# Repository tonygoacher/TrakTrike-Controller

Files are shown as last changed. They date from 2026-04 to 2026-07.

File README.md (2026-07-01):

# TrakTrike-Controller

<p align="center">
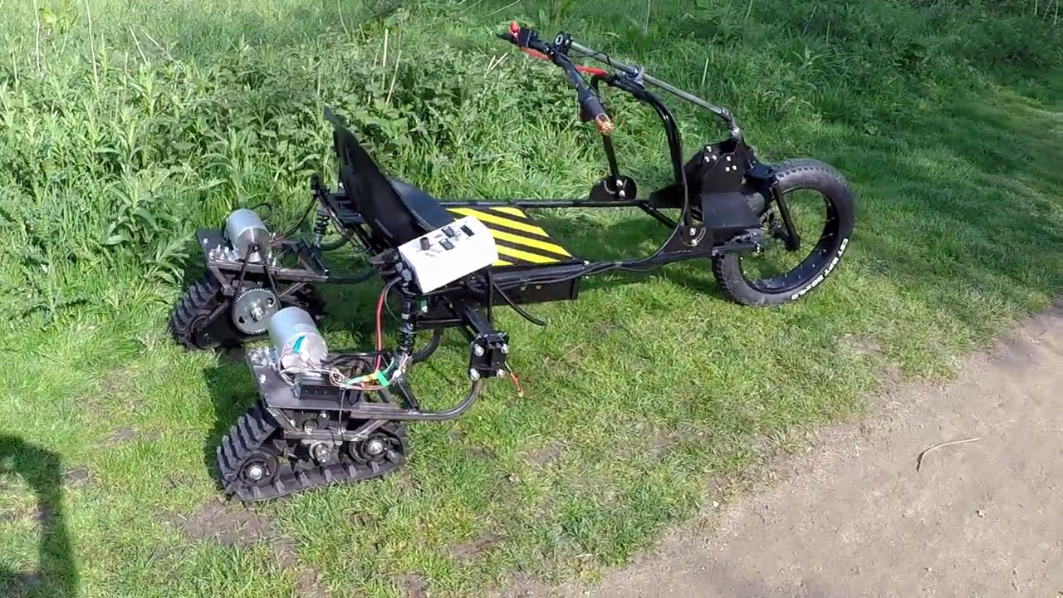
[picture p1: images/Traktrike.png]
  
</p>p>  

<p align="center">
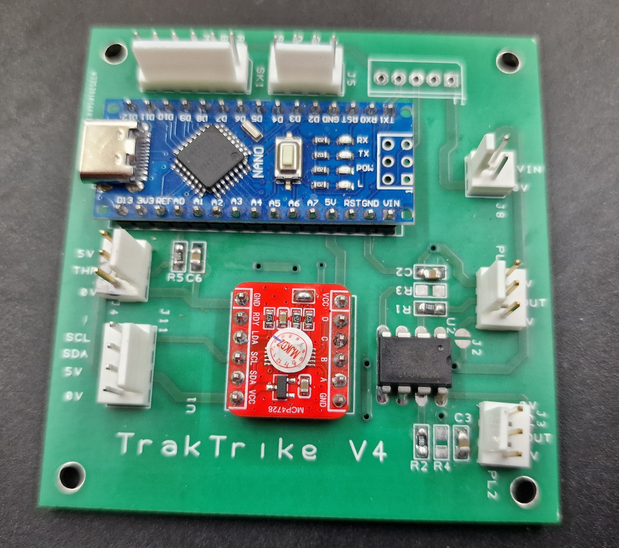
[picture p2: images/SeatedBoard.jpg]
  
</p>

Project files at: https://github.com/tonygoacher/TrakTrike-Controller

An Arduino Nano based dual-track pusher vehicle controller designed for dual motor drive platforms and similar projects that use low cost Aliexpress style BLDC motor controllers.

GCODE files for PCB manufacture and DesignSpark files are included.

The PCB is designed as a drop-in interface between the vehicle controls and a pair of BLDC motor controllers.

[I created TrakTrike, a electrically-driven dual-track sit-on trike for EMF camp 2022.](https://hackaday.io/project/205248-electric-tracked-tricycle-for-emf-camp)

Initially I used VESC75100 clones for the motor controllers. These gave me a great way of controlling accel/decel profiles on a per motor basis...but, I found them very fragile..having destroyed one pair just by changing some parameters and a second pair at WHY2025 for no reason I ever worked out.

At WHY2025 I met some members of [Hacky Racers](https://hackyracers.co.uk/) who suggested trying the inexpensive BLDC controllers available from AliExpress.

While these controllers were surprisingly robust and inexpensive, their low-speed throttle behaviour was poor. The vehicle was difficult to manoeuvre accurately OR SAFELY at low throttle positions.

TrakTrike-Controller was developed to solve that problem.

The controller transforms the behaviour of inexpensive BLDC controllers by providing configurable throttle shaping, ramp control and speed limiting.
The result is a tracked vehicle that is significantly easier and safer to manoeuvre at low speed.

The controller sits above the BLDC motor controllers and is responsible for:

- Throttle processing

- Drive profile management

- Track trim compensation

- Throttle Calibration

- Mode handling

- DAC output generation

The project uses an MCP4728 quad DAC to generate precise analogue throttle signals for independent left and right motor control.

---

# Features

## Drive Profiles

The controller supports multiple operating profiles:
| Profile | Purpose |
|--|--|
|Normal  | Full-speed operation |
|Slow | Manoeuvring mode |
| Reverse  | Reduced-speed reversing |
| Brake  | Rapid deceleration |
| Force | Calibration mode |

Profiles control:

- Throttle response curve

- Acceleration rate

- Deceleration rate

- Maximum DAC output

---

## Throttle Processing

Throttle input passes through several stages:

1. ADC filtering

2. Deadband removal

3. Soft take-up region

4. Configurable throttle curve

5. Ramp limiting

6. Trim compensation

---

## Track Trim Compensation

The controller uses a trim calibration table containing correction values across the throttle range. During operation, trim values are interpolated and

applied smoothly to compensate for differences between the left and right drive systems as the throttle moves through its full range.

---

## EEPROM Configuration

Configuration is stored in EEPROM and protected by:

- Version checking

- CRC validation

Stored settings include:

- DAC start values

- Maximum DAC values

- Slow mode DAC limits

- Throttle calibration

- Trim calibration table

---

## Why an MCP4728?

Many Arduino vehicle controllers generate throttle voltages using filtered PWM outputs.

This project uses an MCP4728 12-bit DAC instead.

Benefits include:

- True analogue outputs

- Higher resolution

- Repeatable calibration

- Independent left/right outputs

- No PWM ripple

---

# Hardware

## Tested Hardware

- Arduino Nano

- MCP4728 Quad DAC

- MCP6002 rail-to-rail op amp (this is used as a voltage follower to 'beef up' the DAC output)

- 16x2 I²C LCD

- Hall-effect twist throttle

- Brake switch

- Reverse switch

- Mode switch

- Dual motor controllers

## System Architecture

```

Twist Throttle

	  ↓

TrakTrike-Controller software

      ↓

MCP4728 DAC

      ↓

BLDC Motor Controllers

      ↓

Left / Right Tracks

```

---

# Operating Modes

## Normal Mode

Full-speed operation using the normal drive profile.

## Slow Mode

Used for precision manoeuvring with reduced maximum speed and gentler acceleration.

## Reverse Mode

Reverse operation automatically uses the slow profile to improve control and safety.

## Brake Mode

Highest-priority operating mode.

When active:

- Brake profile is selected

- Drive output is reset

- Vehicle decelerates rapidly

## Force Mode

Calibration mode used to apply a fixed throttle value independently of the twist throttle.

---

# Calibration Procedure

Connect the USB serial port of the arduino to a PC and run a monitor program (The one built into the Arduino IDE or PlatformIO is ok)

## Throttle Calibration Commands

```

**ENSURE THE VEHICLE IS LIFTED TO PREVENT MOVEMENT DURING THIS PROCEDURE. THE DRIVE MOTORS WILL BE ACTIVATED!**

cal min (Set the minimum throttle input value)

cal max (Set the maximum throttle input value)

cal apply (Apply the above calibration values with some sanity checks)

```

1. Set the physical throttle to its minumum setting

2. Issue the ```cal min ``` command.

3. Set the physical throttle to its maximum position.

4. Issue the ```cal max``` command.

5. Issue the ```cal apply``` command. This will ensure the min is greater than max and save the values to EEPROM.

## Start DAC calibration

**ENSURE THE VEHICLE IS LIFTED TO PREVENT MOVEMENT DURING THIS PROCEDURE. THE DRIVE MOTORS WILL BE ACTIVATED!**

Most BLDC controllers will begin to rotate the motor at some non-zero throttle voltage.

To maximise the throttle range we need to set the start values.

The procedure for left and right is the same. Note. If the motors are turning when the throttle is in the minimum position, your startdac value is too high!

Example: Setting the left side start DAC value

Issue the command

```startl 1000```

Did the motor turn? If no, repeat with higher values until it does, then gradually reduce the value until the motor no longer turns.

If the motor turns with ```startl 1000```, gradually reduce the value until it doesn't.

Repeat for right side using ```startr``` command.

When left and right start dac values have been found issue the

```show```

command to double check the values as printed. Then

```save```

to write to EEPROM.

## Max DAC calibration

**ENSURE THE VEHICLE IS LIFTED TO PREVENT MOVEMENT DURING THIS PROCEDURE. THE DRIVE MOTORS WILL BE ACTIVATED!**

Optional equipment: Tachometer

This sets the DAC output value at which the motors go at full speed. This reduces any 'dead' area where speed does not increase towards the maximum twist throttle position.

1. Disconnect the motor you are not testing.

2. Issue ```force 1.0``` command to set motor to full speed.

3. Issue ```dacmaxl nnnn``` or ```dacmaxr nnnn``` depending on which side you are calibrating where ```nnnn``` is an integer. Start at, say, 2000

4. Did the motor speed increase or decrease (I find this to be audibly detectable, but use a tacho if you wish). If it increases, repeat with a higher value until the motor speed does not increase, then reduce the value until it does. Find the minimum value above which there is no increase.

5. Repeat steps 1..4 for the other motor.

6. Issue ```save``` command to save these values to EEPROM.

## Trim Calibration Procedure

**Required equipment: tachometer**

By forcing the throttle value to a pre-defined set of values which define the interpolation points, the trim table is created .

**ENSURE THE VEHICLE IS LIFTED TO PREVENT MOVEMENT DURING TRIM. THE DRIVE MOTORS WILL BE ACTIVATED!**

Issue the ```show``` command. The device will print a table of the current trim points and the current trim values :

Trims:  
| Point   | Value  |
|--|--|
| 0.0  |  0.17|
|0.1  |0.19|
|0.2  |0.17  |
| 0.3 | 0.18 |
| 0.4 |0.19  |
|  0.5| 0.22 |
| 0.6 | 0.25 |
| 0.7 |0.24  |
| 0.8 |0.27|
| 0.9 |0.3|
|1.0  |0.31|

For each entry in the point column, issue a force command. e,g.

```force 0.5```

Measure left and right track RPM. Then issue the

```calibrate <leftRPM> <rightRPM>```

Command, eg

```calibrate 120 125```

Repeat for all rows. It's ok to go back to a previous point value and re-calibrate just that point.

When all points have been calibrated. Issue the ```show``` command to review the values. If all looks OK, issue the

```save``` command to write to EEPROM.

## Slow Mode Max DAC values

This is the value that sets the maximum voltage that the DAC will output at full throttle in slow mode. The default of 1500 is a sensible value for BLDC controllers but if your vehicle is too fast or too slow at max throttle, you can increase the value using the

```slowmaxl``` and ```slowmaxr``` commands.

e.g.

```slowmaxl 1500```

Sets the slow mode speed to 1500. 
Issue the
```save``` 
command to write to EEPROM.

Test the value on the vehicle and increase/decrease as required. I found it sensible to have both left and right values the same. You may need different values.

# Serial Commands

## Configuration

```text

load // Reload the current EEPROM settings

save // Save the current configuration to EEPROM

defaults // Restore all configuration values to defaults

show // Show the trim and DAC max values

showall // Show all config values. A lot of these can only be changed in the software.

```

## DAC Start Values

```text

startl 1060

startr 1060

```

## Maximum DAC Values

```text

dacmaxl 3500

dacmaxr 3500

```

## Slow Mode DAC Limits

```text

slowmaxl 1080

slowmaxr 1080

```

## Force Output

```text

force 0.25

force 0.50

force 0.75

```

---

# Safety Features

## Startup Throttle Inhibit

Some motor controllers refuse to operate if throttle voltage is present during startup.

To accommodate this behaviour, the controller forces both DAC outputs to 0V during power-up before normal operation begins.

## Throttle Fault Detection

Out-of-range throttle readings are detected automatically and result in zero throttle output.

## Configuration Validation

Stored settings are protected using:

- Version checking

- CRC validation

Invalid configurations automatically revert to defaults.

---

# Building

Developed using:

- PlatformIO

- Arduino Framework

- Arduino Nano

Required libraries:

- Adafruit MCP4728

- LiquidCrystal_I2C

Project-specific support classes:

- Switch

- SmoothBarGraph

- Pacer

---

# Project Status

This controller is actively used on a real tracked electric vehicle and continues to evolve through practical testing and field experience.

Contributions, bug reports and suggestions are welcome.

---

# License

This project is licensed under the MIT license.

---

*"Many design decisions in this project were driven by real-world testing rather than simulation."*

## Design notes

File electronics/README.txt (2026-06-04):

The design files were created with DesignSpark PCB
https://www.rs-online.com/designspark/pcb-software

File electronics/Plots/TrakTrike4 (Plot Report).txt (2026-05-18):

Plot Report
-----------

Report Written:     15:25 Wednesday, April 29, 2026
Project Path:       N:\TrakTrikeElectronics4\electronics\TrakTrike4.prj
Design Path:        N:\TrakTrikeElectronics4\electronics\TrakTrike4.pcb
Design Title:       
Created:            19/04/2026 11:54:32
Last Saved:         29/04/2026 15:24:48
Editing Time:       520 min
Units:              mm (precision 1)

Device Settings
===============

Gerber Settings
===============

    Leading zero suppression.
    G01 assumed throughout.
    Line termination <*> <CR> <LF>.
    3.5 format absolute inches.

    Format commands defined in Gerber file.
    Aperture table defined in Gerber file.
    Hardware arcs allowed.

Drill Settings
==============

    Excellon Format 2
    Format 3.5 absolute in mm.
    Zero suppression Leading

Plots Output
============

    Plot Job: "N:\TrakTrikeElectronics4\electronics\TrakTrike4.mop"

Gerber Output
=============

N:\TrakTrikeElectronics4\electronics\Plots\TrakTrike4 - Top Silkscreen.gbr

    Layers:
    ------------------
    Top Silkscreen

    D-Code Shape  (thou)
    -----------------------
    D10    Round 7.87
    D11    Round 11.81
    D12    Round 5.00
    D13    Round 1.00
    D14    Round 10.00

Gerber Output
=============

N:\TrakTrikeElectronics4\electronics\Plots\TrakTrike4 - Top Copper.gbr

    Layers:
    ------------------
    Top Copper
    Board Outlines

    D-Code Shape  (thou)
    --------------------------------------------------
    D12    Round 5.00
    D15    Round 50.00
    D16    Round 31.50
    D17    Round 56.00
    D18    Round 48.00
    D19    Round 137.80
    D70    Rectangle 59.06 X 98.43  Rotation 90
    D71    Oval 59.06 X 98.43  Rotation 90
    D20    Rounded Rectangle 66.93 X 118.11 X 23.62
    D21    Rectangle 66.93 X 118.11
    D22    Oval 60.00 X 110.00  Rotation 90
    D23    Rectangle 70.87 X 118.11
    D24    Oval 70.87 X 118.11
    D25    Bullet 78.74 X 39.37  Rotation 270
    D26    Round 78.74
    D27    Bullet 78.74 X 39.37  Rotation 90
    D28    Rectangle 55.00 X 60.00
    D29    Rectangle 55.00 X 60.00  Rotation 90
    D72    Rectangle 62.99 X 137.80  Rotation 90
    D73    Oval 62.99 X 137.80  Rotation 90
    D74    Rectangle 62.99 X 137.80
    D75    Oval 62.99 X 137.80
    D76    Rectangle 78.74 X 118.11  Rotation 90
    D77    Oval 78.74 X 118.11  Rotation 90
    D78    Square 78.74
    D79    Octagon 78.74

Gerber Output
=============

N:\TrakTrikeElectronics4\electronics\Plots\TrakTrike4 - Top Copper (Resist).gbr

    Layers:
    --------------
    Top Copper

    D-Code Shape  (thou)
    --------------------------------------------------
    D80    Round 147.80
    D81    Rectangle 69.06 X 108.43  Rotation 90
    D82    Oval 69.06 X 108.43  Rotation 90
    D83    Rounded Rectangle 66.93 X 118.11 X 23.62
    D84    Rectangle 76.93 X 128.11
    D85    Oval 70.00 X 120.00  Rotation 90
    D86    Rectangle 80.87 X 128.11
    D87    Oval 80.87 X 128.11
    D88    Bullet 88.74 X 49.37  Rotation 270
    D89    Round 88.74
    D90    Bullet 88.74 X 49.37  Rotation 90
    D91    Rectangle 65.00 X 70.00
    D92    Rectangle 65.00 X 70.00  Rotation 90
    D93    Rectangle 72.99 X 147.80  Rotation 90
    D94    Oval 72.99 X 147.80  Rotation 90
    D95    Rectangle 72.99 X 147.80
    D96    Oval 72.99 X 147.80
    D97    Rectangle 88.74 X 128.11  Rotation 90
    D98    Oval 88.74 X 128.11  Rotation 90
    D99    Square 88.74
    D100   Octagon 78.74

Gerber Output
=============

N:\TrakTrikeElectronics4\electronics\Plots\TrakTrike4 - Top Paste Mask.gbr

    Layers:
    ------------------
    Top Paste Mask

    D-Code Shape  (thou)
    ----------------------------------------------
    D101   Bullet 72.74 X 33.37  Rotation 270
    D102   Round 72.74
    D103   Bullet 72.74 X 33.37  Rotation 90
    D104   Rectangle 49.00 X 54.00
    D105   Rectangle 49.00 X 54.00  Rotation 90

Gerber Output
=============

N:\TrakTrikeElectronics4\electronics\Plots\TrakTrike4 - Bottom Copper.gbr

    Layers:
    -----------------
    Bottom Copper

    D-Code Shape  (thou)
    --------------------------------------------------
    D15    Round 50.00
    D16    Round 31.50
    D17    Round 56.00
    D18    Round 48.00
    D19    Round 137.80
    D70    Rectangle 59.06 X 98.43  Rotation 90
    D71    Oval 59.06 X 98.43  Rotation 90
    D20    Rounded Rectangle 66.93 X 118.11 X 23.62
    D21    Rectangle 66.93 X 118.11
    D22    Oval 60.00 X 110.00  Rotation 90
    D23    Rectangle 70.87 X 118.11
    D24    Oval 70.87 X 118.11
    D28    Rectangle 55.00 X 60.00
    D29    Rectangle 55.00 X 60.00  Rotation 90
    D72    Rectangle 62.99 X 137.80  Rotation 90
    D73    Oval 62.99 X 137.80  Rotation 90
    D74    Rectangle 62.99 X 137.80
    D75    Oval 62.99 X 137.80
    D76    Rectangle 78.74 X 118.11  Rotation 90
    D77    Oval 78.74 X 118.11  Rotation 90
    D78    Square 78.74
    D79    Octagon 78.74

Gerber Output
=============

N:\TrakTrikeElectronics4\electronics\Plots\TrakTrike4 - Bottom Silkscreen.gbr

    Layers:
    ---------------------
    Bottom Silkscreen

    D-Code Shape  (thou)
    -----------------------
    D12    Round 5.00

Gerber Output
=============

N:\TrakTrikeElectronics4\electronics\Plots\TrakTrike4 - Bottom Solder Mask.gbr

    Layers:
    ----------------------
    Bottom Solder Mask

    D-Code Shape  (thou)
    --------------------------------------------------
    D106   Round 62.00
    D107   Round 54.00
    D108   Round 143.80
    D109   Rectangle 65.06 X 104.43  Rotation 90
    D110   Oval 65.06 X 104.43  Rotation 90
    D111   Rounded Rectangle 66.93 X 118.11 X 23.62
    D112   Rectangle 72.93 X 124.11
    D113   Oval 66.00 X 116.00  Rotation 90
    D114   Rectangle 76.87 X 124.11
    D115   Oval 76.87 X 124.11
    D116   Rectangle 61.00 X 66.00  Rotation 90
    D117   Rectangle 61.00 X 66.00
    D118   Rectangle 68.99 X 143.80  Rotation 90
    D119   Oval 68.99 X 143.80  Rotation 90
    D120   Rectangle 68.99 X 143.80
    D121   Oval 68.99 X 143.80
    D122   Rectangle 84.74 X 124.11  Rotation 90
    D123   Oval 84.74 X 124.11  Rotation 90
    D124   Square 84.74
    D125   Octagon 78.74

Gerber Output
=============

N:\TrakTrikeElectronics4\electronics\Plots\TrakTrike4 - Bottom Paste Mask.gbr

    Layers:
    ---------------------
    Bottom Paste Mask

    D-Code Shape  (thou)
    ----------------------------------------------
    D104   Rectangle 49.00 X 54.00
    D105   Rectangle 49.00 X 54.00  Rotation 90

Gerber Output
=============

N:\TrakTrikeElectronics4\electronics\Plots\TrakTrike4 - Gerber Drill Data - [Through Hole].gbr

    Layers:
    ------------------
    [Through Hole]

    D-Code Shape  (thou)
    -----------------------
    D126   Round 32.00
    D127   Round 24.00
    D128   Round 125.98
    D129   Round 39.37
    D130   Round 43.31
    D131   Round 35.00

NC Drill Output
===============

N:\TrakTrikeElectronics4\electronics\Plots\TrakTrike4 - NC Drill Data - [Through Hole].drl

    Output:
    ---------------------------
    Plated Round Drill Holes
    Plated Slots

    Tool  Size           Count   ID
    --------------------------------------
    T001  0.02400 inches 1     A
    T002  0.03200 inches 17    F
    T003  0.03500 inches 5     D
    T004  0.03937 inches 56    H
    T005  0.04331 inches 11    P
    T006  0.12598 inches 4     C
    --------------------------------------
    Total                94
    --------------------------------------

N:\TrakTrikeElectronics4\electronics\Plots\TrakTrike4 - NC Drill Data - [Through Hole] (Unplated).drl

    Output:
    -----------------------------
    Unplated Round Drill Holes
    Unplated Slots

    Tool  Size Count   ID
    ----------------------------
    ----------------------------
    Total      0
    ----------------------------

End Of Report.

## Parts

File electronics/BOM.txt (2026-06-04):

C1..C6 0.1uF 0805 
R1, R2	1K 1% 0805
R3, R4 (optional) 10K 1% 0805
U1 MCP4728 DAC module. (https://www.aliexpress.com/item/1005010677659091.html)
U2 MCP6002 8 pin DIP. Make sure you get these from a reliable source. I got fake ones off AliExpress and they do not have full rail to rail output.
U3 Arduino Nano 

Apologies for all the oddball connector identifiers!

J1 Molex KK 5 way header 22-27-2051
J11, J5 Molex KK 254 4 way header 22-23-2041 
PL1, PL2, J4 Molex 3 way KK 254 3 way header 22-27-2031
SK1 Molex KK 254 6 way header 22-27-2061
J8 Molex KK 254 2 way header 22-23-2021

2.54 mm strip headers for Arduino and DAC x 4
https://www.aliexpress.com/item/1005006034877497.html

LCD1602 I2C line LCD display  https://www.aliexpress.com/item/1005006964073869.html

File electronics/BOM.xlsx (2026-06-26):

 |  |  | xxxx xxxx xxxxx xxPCS BOM (Sample Bill of Materials)
Item # | *Designator | *Qty | Manufacturer | *Mfg Part # | Description / Value | *Package/Footprint | Type | Your Instructions / Notes
1 | U1 | 1 | Aliexpress | MCP4728 DAC Module | MCP4728 DAC Module.DIP Format | PDIP 12 | thru-hole | https://www.aliexpress.com/item/1005010705047519.html
2 | U2 | 1 | Microchip | MP6002 | Dual Op Amp 8 pin DIP | DIP | thru-hole
3 | U3 | 1 | Arduino | "7630049200173" | Arduino Nano 3.x | DIP | thru-hole
4 | C1-C6 | 6 | Kyocera AVX | 08055C104JAT2A | 0.1uF Ceramic capacitor SMD 5% | 805 | SMD
5 | R1,R2 | 2 | PANASONIC | ERA6ARB102V | 1K SMD Chip resistor 0.1% | 805 | SMD
6 | R3,R4 | 2 | VISHAY | TNPW080510K0BEEA | 10K SMD Chip resistor 0.1% | 805 | SMD
7 | J1 | 1 | Molex | 22-27-2051 | 5 way 2.54" square pin Header | SIL5 | thru-hole
8 | J11, J5 | 1 | Molex | 22-23-2041 | 4 way 2.54" square pin header | SIL4 | thru-hole
9 | PL1, PL2 , J4 | 3 | Molex | 22-27-2031 | 3 way 2.54" square pin header | SIL3 | thru-hole
10 | J8 | 1 | Molex | 22-23-2021 | 2 way 2.54" square pin header | SIL2 | thru-hole
11 | SK1 | 1 | Molex | 22-27-2061 | 6 way 2.54" square pin header
12
13
14
15
Need a quick and accurante quote? Need an efficient production? Please read SMT Ordering Necessary Files & Info in 1 minute. Thank you very much! (https://www.pcbway.com/smt_ordering_guide.html)
Click for Instructions on How to Create a BOM (https://www.pcbway.com/blog/PCB_Assembly/How_to_Build_a_BOM__Bill_Of_Materials_.html)

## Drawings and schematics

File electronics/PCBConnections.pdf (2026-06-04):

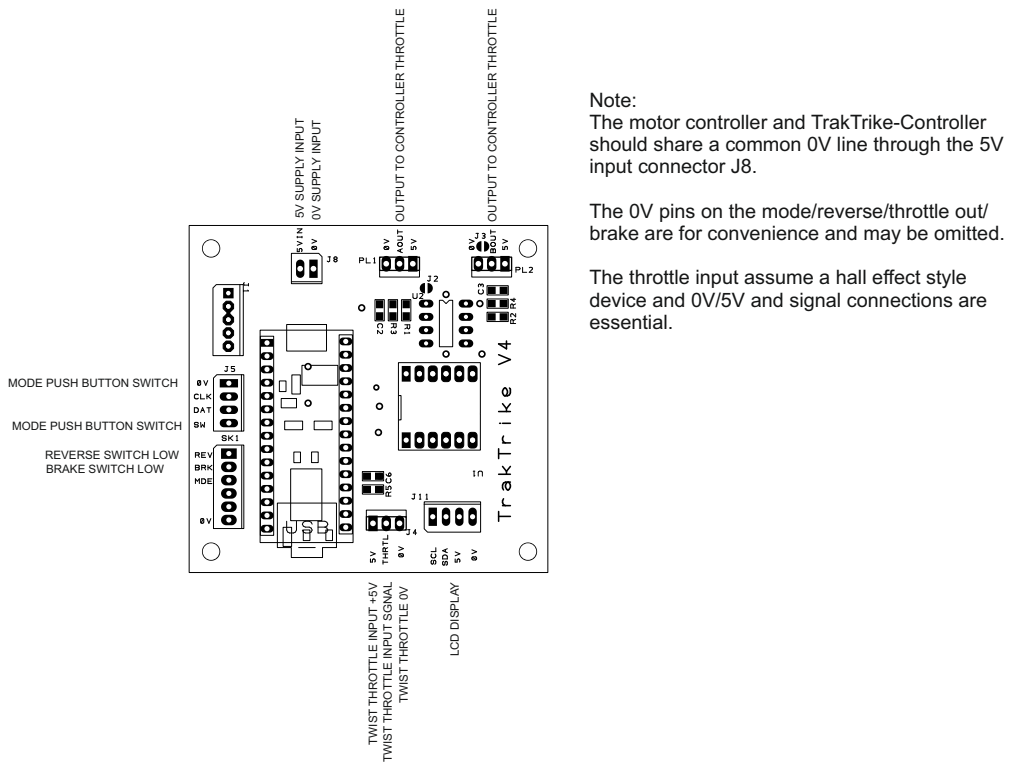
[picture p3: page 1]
TWIST THROTTLE 0V; LCD DISPLAY; 5V SUPPLY INPUT; 0V SUPPLY INPUT; TrakTrike-Controller

OUTPUT TO CONTROLLER THROTTLE

Note:
The motor controller and
should share a common 0V line through the 5V
input connector J8.

The 0V pins on the mode/reverse/throttle out/
brake are for convenience and may be omitted.

The throttle input assume a hall effect style
device and 0V/5V and signal connections are
essential.

MODE PUSH BUTTON SWITCH

REVERSE SWITCH LOW
BRAKE SWITCH LOW

TWIST THROTTLE INPUT +5V

TWIST THROTTLE INPUT SGNAL

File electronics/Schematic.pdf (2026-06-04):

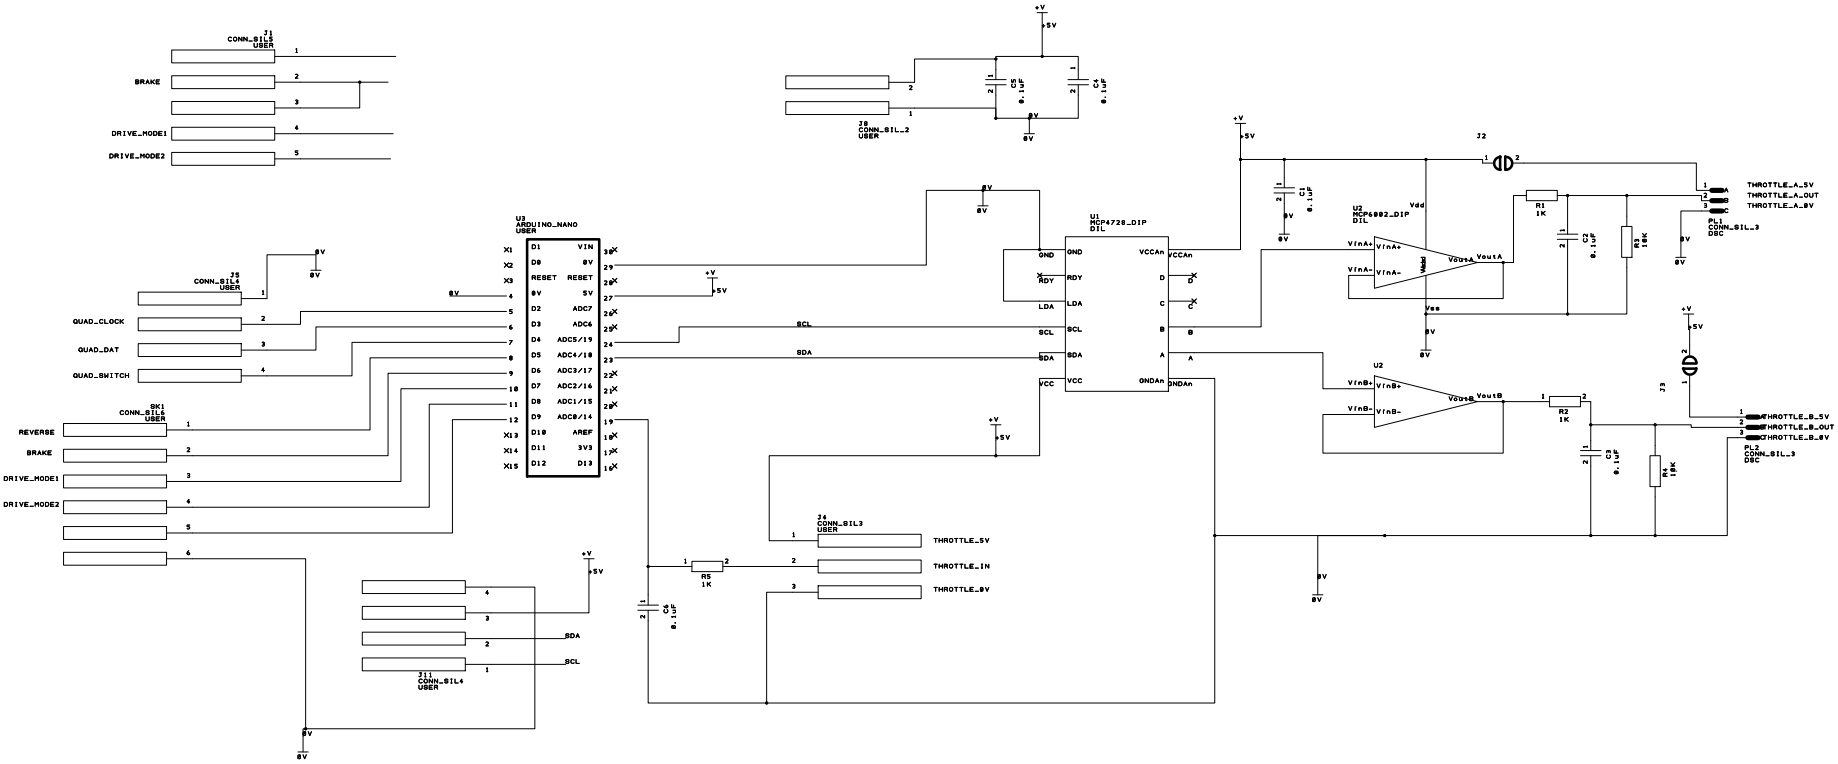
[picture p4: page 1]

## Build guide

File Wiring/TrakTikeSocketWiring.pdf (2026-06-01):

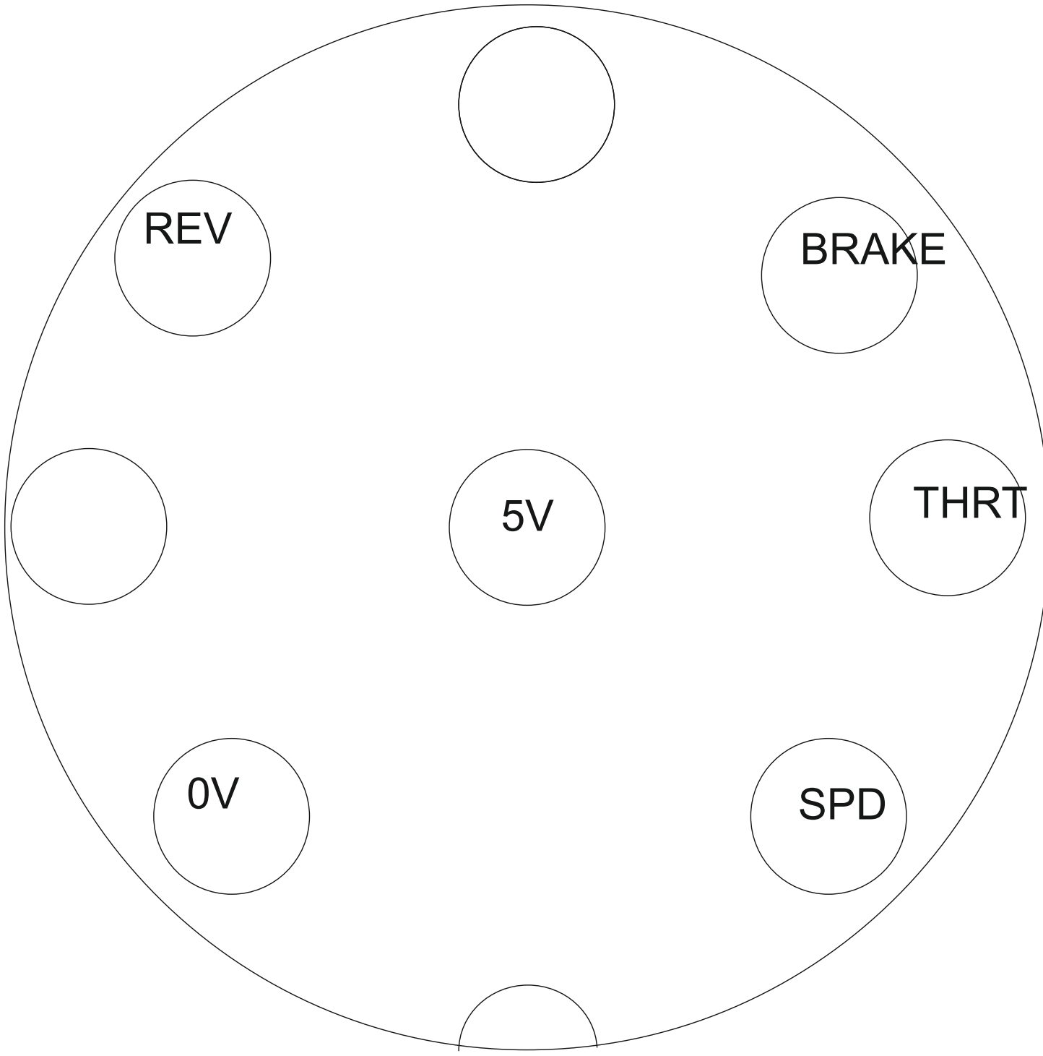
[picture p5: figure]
SPD; THRT; BRAKE REV

Looking into back of
M12 socket

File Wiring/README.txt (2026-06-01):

This is all intended for my use. Please ignore.

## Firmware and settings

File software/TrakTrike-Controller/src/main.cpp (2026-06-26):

/******************************************************************************
 *
 *  TrakTrike-Controller
 *
 *  An Arduino Nano based dual-track vehicle controller for tracked electric
 *  vehicles, skid-steer platforms and similar projects using analogue
 *  throttle controlled BLDC motor controllers.
 *
 *  Features:
 *      - Configurable throttle shaping
 *      - Multiple drive profiles
 *      - Track trim calibration and interpolation
 *      - Dual MCP4728 DAC outputs
 *      - EEPROM configuration storage
 *      - Throttle calibration and diagnostics
 *
 *  Author:
 *      Tony Goacher
 *
 *  Project:
  *     https://github.com/tonygoacher/TrakTrike-Controller
 *
 *  Copyright:
 *      Copyright (c) 2026 Tony Goacher
 *
 *  License:
 *      Released under the MIT License.
 *
 *  Disclaimer:
 *      This software controls equipment capable of movement and may cause
 *      injury, death, or property damage if used incorrectly.
 *
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
 *      Users are solely responsible for ensuring that the software and hardware is
 *      suitable for their application and that appropriate safety measures
 *      are implemented and tested before use.
 *
 *      Always test with drive wheels or tracks lifted clear of the ground
 *      before operating a vehicle under software control.
 *
 ******************************************************************************/

#include <Arduino.h>
#include <EEPROM.h>
#include <Wire.h>
#include <stddef.h>


#include <LiquidCrystal_I2C.h>
#include <math.h>
#include <Adafruit_MCP4728.h>
#include "ports.h"

#include "Switch.h"
#include "SmoothBarGraph.h"
#include "Pacer.h"



// =====================
// MCP4728
// =====================
Adafruit_MCP4728 mcp;
constexpr int   MinDACValue = 0;
constexpr int   MaxDACValue = 4095;
constexpr float DAC_VREF    = 4.7f;

// =====================
// CONFIG
// =====================
#define EEPROM_ADDR 0
#define PARAM_VERSION 7
#define NUM_TRIM_VALUES 11

#define STATS_UPDATE_MS 1000    // Update stats this many ms
#define BARGRAPH_UPDATE_MS 100  // Update bargraph this many ms

LiquidCrystal_I2C lcd(0x27,16,2);  // set the LCD address to 0x27 for a 16 chars and 2 line display
SmoothBarGraph barGraph(lcd,6,1,10);

struct DriveProfile
{
    float curveExponent;
    float rampUp;
    float rampDown;
};




DriveProfile normalProfile =
{
    1.3f,   // curve
    0.05f,  // ramp up
    0.8f    // ramp down
};

DriveProfile slowProfile =
{
    1.5f,   // softer curve
    0.005f,  // gentler ramp
    0.15f    // Ramp down
};

DriveProfile brakeProfile =
{
    0.0f,   // softer curve
    0.0f,  // gentler ramp
    1.0f    // HArd decel
};


// Use force command to set these values Then measure both motor speeds.
// The use calibrate lefftrpm rightrpm to set the TRIM_VALUE entry. Index into TRIM_VALUE is calculated automatically
const float trimThrottlePoints[NUM_TRIM_VALUES] =
{
    0.0f,
    0.1f,
    0.2f,
    0.3f,
    0.4f,
    0.5f,
    0.6f,
    0.7f,
    0.8f,
    0.9f,
    1.0f
};

// This can be used to override the twist throttle value during trim calibration. BRAKEMODE overrides this.
float FORCE_OUTPUT  = 0.0f;

// Default trim calibration values. These are for my EV. 
// You probably need to do the calibration routine to find your defaults
const float defaultCalibration[NUM_TRIM_VALUES] = 
{
    0.17,
    -0.16,
    0.03,
    0.08,
    0.12,
    0.19,
    0.16,
    0.10,
    0.17,
    0.17,
    0.17,
};

enum TRACK_ID
{
    LEFT = 0,
    RIGHT = 1
};

enum SystemMode
{
    SLOWMODE = 1,
    BRAKEMODE = 2,
    REVERSEMODE = 4,
    FORCEMODE = 8,
    MODECHANGE = 16,
 

    INIT = 0xff
};

// Pending mode state being assembled by SetModes().
// Changes are committed to systemMode by
// displayNewSystemMode() after one-shot actions
// (LCD updates, output resets, etc.) have been performed.
uint8_t newSystemMode = SystemMode::SLOWMODE; 

// Current active mode state.
// Used to detect mode transitions and drive the LCD display.
uint8_t currentSystemMode = SystemMode::INIT;  

 // When changing mode, force the throttle to zero for 500ms or continuously until throttle released
// This prevents unwanted movement if reverse is enabled at none aero throttle
Pacer modePacer(false,500);   

typedef struct {
    uint8_t  version;
    uint16_t crc;
} config_header_t;

struct settings_t
{
    int LEFT_DAC_START;
    int LEFT_DAC_MAX;
    int LEFT_SLOW_DAC_MAX;
    int RIGHT_DAC_START;
    int RIGHT_DAC_MAX;
    int RIGHT_SLOW_DAC_MAX;
    int LEFT_DEFAULT;
    int RIGHT_DEFAULT;

    float THROTTLE_DEADBAND;
    float TAKEUP_END;

    float TRIM_VALUES[NUM_TRIM_VALUES];


    int THROTTLE_MIN_ADC;
    int THROTTLE_MAX_ADC;
    uint8_t DAC_DEFAULT_WRITTEN;       // This is used to track if the default DAC output has been written to the DAC EEPROM
};

struct Config {
    config_header_t header;
    settings_t  settings;
   
};

Config cfg;



// Declare forward refs
void  loadDefaults();


void printTrimValues( const float v[NUM_TRIM_VALUES])
{
    for(int i = 0 ; i < NUM_TRIM_VALUES ; i++)
    {   
       Serial.println(v[i]);
    }
}

// =====================
// THROTTLE CLASS
// =====================
class TwistThrottle {
public:
    struct Config {
        int minADC;
        int maxADC;
        int deadband;
        float filterAlpha;
        float maxRate;
    };

    void begin(const Config& cfg) {
        config = cfg;
        filtered = config.minADC;
        lastOutput = 0.0f;
        lastTime = millis();
    }

    float GetThrottle() {

        int raw = analogRead(THROTTLE);

        int validMin = config.minADC - 20;
        int validMax = config.maxADC + 20;

        if (raw < validMin || raw > validMax) 
        { 
            fault = true; return 0.0f; 
        }

        fault = false;

        filtered += (raw - filtered) * config.filterAlpha;

        if (filtered < (config.minADC + config.deadband)) {
            return applyRateLimit(0.0f);
        }

        float output = (filtered - (config.minADC + config.deadband)) /
                       (float)(config.maxADC - (config.minADC + config.deadband));

        output = constrain(output, 0.0f, 1.0f);

        return applyRateLimit(output);
    }

    bool isFault() const {
        return fault;
    }

private:
    Config config;

    float filtered = 0.0f;
    float lastOutput = 0.0f;
    unsigned long lastTime = 0;

    bool fault = false;

    float applyRateLimit(float target) {

        if (config.maxRate <= 0.0f)
            return target;

        unsigned long now = millis();
        float dt = (now - lastTime) / 1000.0f;
        lastTime = now;

        float maxDelta = config.maxRate * dt;
        float delta = target - lastOutput;

        if (delta > maxDelta) delta = maxDelta;
        if (delta < -maxDelta) delta = -maxDelta;

        lastOutput += delta;

        return lastOutput;
    }
};

TwistThrottle throttle;

// =====================
// CALIBRATION STATE
// =====================
struct ThrottleCal {
    int minADC = 1023;
    int maxADC = 0;
};

ThrottleCal throttleCal;

// =====================
// STATE
// =====================

String inputString = "";
Switch modeSwitch(MODE);


// =====================
// FORWARD DECLARATIONS
// =====================
void processCommand(String cmd);
void updateDACDefaults();
void applyCalibration();
void configureThrottle();
void printParams();

void printAll(const Config& cfg)
{
    Serial.println(F("===== CONFIG ====="));

    Serial.print(F("Version: "));
    Serial.println(cfg.header.version);

    Serial.print(F("CRC: "));
    Serial.println(cfg.header.crc);

    Serial.println();

    Serial.print(F("LEFT DAC_START: "));
    Serial.println(cfg.settings.LEFT_DAC_START);
    Serial.print(F("RIGHT DAC_START: "));
    Serial.println(cfg.settings.RIGHT_DAC_START);    

    Serial.print(F("LEFT_DAC_MAX: "));
    Serial.println(cfg.settings.LEFT_DAC_MAX);
    
    Serial.print(F("LEFT_SLOW_DAC_MAX: "));
    Serial.println(cfg.settings.LEFT_SLOW_DAC_MAX);

    Serial.print(F("RIGHT DAC_MAX: "));
    Serial.println(cfg.settings.RIGHT_DAC_MAX);

    Serial.print(F("RIGHT_SLOW_DAC_MAX: "));
    Serial.println(cfg.settings.RIGHT_SLOW_DAC_MAX);

    Serial.println();

    Serial.print(F("THROTTLE_DEADBAND: "));
    Serial.println(cfg.settings.THROTTLE_DEADBAND, 4);

    Serial.print(F("TAKEUP_END: "));
    Serial.println(cfg.settings.TAKEUP_END, 4);

    Serial.println();

    Serial.println();

    Serial.println(F("Config trim values"));
    printTrimValues( cfg.settings.TRIM_VALUES);
    

    Serial.print(F("THROTTLE_MIN_ADC: "));
    Serial.println(cfg.settings.THROTTLE_MIN_ADC);

    Serial.print(F("THROTTLE_MAX_ADC: "));
    Serial.println(cfg.settings.THROTTLE_MAX_ADC);

    Serial.println(F("=================="));
}

// =====================
// CRC
// =====================
uint16_t calculateCRC(const settings_t &cfg) {
    const uint8_t *data = (const uint8_t*)&cfg;

    size_t len   = sizeof(settings_t) ;

    uint16_t crc = 0;

    for (size_t i = 0; i < len; i++) {
        crc += data[i];
    }

    return crc;
}

// =====================
// CONFIG APPLY
// =====================
void applyConfig(const Config &new_cfg) {

    
    cfg = new_cfg;
    printAll(cfg);
}

// =====================
// CONFIG SAVE/LOAD
// =====================
void saveConfig() {
  

    cfg.header.version = PARAM_VERSION;


    cfg.header.crc = calculateCRC(cfg.settings);

    EEPROM.put(EEPROM_ADDR, cfg);

    Serial.println("Saved config");
}

bool loadConfig() {
    Config loadedConfig;
    EEPROM.get(EEPROM_ADDR, loadedConfig);

    if (loadedConfig.header.version != PARAM_VERSION) 
    {
        Serial.println("Config version mismatch. Using defaults");
        loadDefaults();
        saveConfig();
        return false;
    }

    if (calculateCRC(loadedConfig.settings) != loadedConfig.header.crc)
    {
      Serial.println("Config load failed CRC. Using defaults");
      loadDefaults();
      saveConfig();
      return false;
    }      

    applyConfig(loadedConfig);

    Serial.println("Loaded config");
    return true;
}

void loadDefaults() {

     cfg.header.version = PARAM_VERSION;
     cfg.header.crc = 0;    // This will be set in the save routine.
     cfg.settings.LEFT_DAC_START = 1060;
     cfg.settings.RIGHT_DAC_START = 1060;
     cfg.settings.LEFT_DAC_MAX = 3500;
     cfg.settings.RIGHT_DAC_MAX = 3500;
     cfg.settings.LEFT_SLOW_DAC_MAX = 1500;
    
     cfg.settings.RIGHT_SLOW_DAC_MAX = 1500;

     cfg.settings.THROTTLE_DEADBAND = 0.05f;
     cfg.settings.TAKEUP_END = 0.20f;


    for(int i = 0 ; i < NUM_TRIM_VALUES ; i++)
    {
         cfg.settings.TRIM_VALUES[i] = defaultCalibration[i];
    }


     cfg.settings.THROTTLE_MIN_ADC = 177;
     cfg.settings.THROTTLE_MAX_ADC = 808;

     cfg.settings.DAC_DEFAULT_WRITTEN = 0;

    Serial.println("Loaded defaults");
    printParams();
    
}

// =====================
// THROTTLE SETUP
// =====================
void configureThrottle() {

    TwistThrottle::Config throttleConfig;

    throttleConfig.minADC =  cfg.settings.THROTTLE_MIN_ADC;
    throttleConfig.maxADC =  cfg.settings.THROTTLE_MAX_ADC;

    throttleConfig.deadband = 8;
    throttleConfig.filterAlpha = 0.1f;
    throttleConfig.maxRate = 0.0f;


    throttle.begin(throttleConfig);
}

// =====================
// CALIBRATION
// =====================


void captureMin() {
    throttleCal.minADC = analogRead(THROTTLE);
    Serial.print(F("Min captured: ")); Serial.println(throttleCal.minADC);
}

void captureMax() {
    throttleCal.maxADC = analogRead(THROTTLE);
    Serial.print(F("Max captured: ")); Serial.println(throttleCal.maxADC);
}

/**
 * Apply the most recently captured throttle calibration values.
 *
 * The calibration process records the minimum and maximum ADC readings
 * observed while the throttle is moved through its full travel. This
 * function validates the captured range, applies a small safety margin,
 * and updates the stored throttle calibration limits.
 *
 * A margin of 5 ADC counts is added to the measured minimum and
 * subtracted from the measured maximum. This prevents normal operation
 * from occurring exactly at the calibration boundaries and provides a
 * small tolerance for ADC noise and component drift.
 *
 * The adjusted values are constrained to the valid ADC range
 * (0-1023) and then checked to ensure a valid throttle span remains.
 *
 * If the resulting range is invalid, the calibration is rejected and
 * detailed diagnostic information is printed to aid troubleshooting.
 *
 * On success, configureThrottle() is called to rebuild any derived
 * parameters used by the throttle processing code.
 */
void applyCalibration()
{
    constexpr int MaxADCValue = 1023;  // This may change depending on yuor hardware
    constexpr int MinADCValue = 0;
    constexpr int CALIBRATION_MARGIN_ADC = 5;   // Gives us some leeway over a noise ADC reading

    // Validate measured calibration range
    if (throttleCal.maxADC <= throttleCal.minADC)
    {
        Serial.println(F("Invalid calibration range"));

        Serial.print(F("Measured Min: "));
        Serial.println(throttleCal.minADC);

        Serial.print(F("Measured Max: "));
        Serial.println(throttleCal.maxADC);

        return;
    }

    // Apply calibration margin and constrain to ADC limits
    int minADC = constrain(throttleCal.minADC + CALIBRATION_MARGIN_ADC, MinADCValue, MaxADCValue);
    int maxADC = constrain(throttleCal.maxADC - CALIBRATION_MARGIN_ADC, MinADCValue, MaxADCValue);

    // Ensure a valid range remains after margins are applied
    if (maxADC <= minADC)
    {
        Serial.println(F("Calibration range too small after margins"));

        Serial.print(F("Measured Min: "));
        Serial.println(throttleCal.minADC);

        Serial.print(F("Measured Max: "));
        Serial.println(throttleCal.maxADC);

        Serial.print(F("Adjusted Min: "));
        Serial.println(minADC);

        Serial.print(F("Adjusted Max: "));
        Serial.println(maxADC);

        return;
    }

    cfg.settings.THROTTLE_MIN_ADC = minADC;
    cfg.settings.THROTTLE_MAX_ADC = maxADC;

    configureThrottle();

    Serial.println(F("Calibration applied"));

    Serial.print(F("Throttle Min ADC: "));
    Serial.println(cfg.settings.THROTTLE_MIN_ADC);

    Serial.print(F("Throttle Max ADC: "));
    Serial.println(cfg.settings.THROTTLE_MAX_ADC);
}


void updateDACDefaults() {


    Serial.println(F("Updating DAC defaults"));

    // Store a power-up default of 0V in the DAC EEPROM.
    // Some motor controllers refuse to enable if any throttle
    // voltage is present during their startup sequence.
    mcp.setChannelValue(MCP4728_CHANNEL_A, 0);
    mcp.setChannelValue(MCP4728_CHANNEL_B, 0);
  
    mcp.setChannelValue(MCP4728_CHANNEL_C, 0);
    mcp.setChannelValue(MCP4728_CHANNEL_D, 0);

    mcp.saveToEEPROM();

}


// The throttle value is always 0.0-1.0. This function returns the maximum DAC value 
// that is to be scaled afgainst the throttle value to get the actual speed. SLOWMODE returns a
// smaller MAXDAC value so we can use the entire mechanical range of the twist throttle but 
// limit the maximum speed that this will result in.
int getMaxDACValue(int trackID)
{
    // Force mode overrides all as it's essential we use the top end DAC output for calibration
    if(((currentSystemMode & SystemMode::SLOWMODE) || (currentSystemMode & SystemMode::REVERSEMODE)) && !(currentSystemMode & SystemMode::FORCEMODE))
    {
        if(trackID == TRACK_ID::LEFT)
        {
            return cfg.settings.LEFT_SLOW_DAC_MAX;
        }
        else
        {
            return cfg.settings.RIGHT_SLOW_DAC_MAX;
        }
    }
    
    return trackID == TRACK_ID::LEFT ? cfg.settings.LEFT_DAC_MAX : cfg.settings.RIGHT_DAC_MAX;

}


// =====================
// TRACK OUTPUT
// =====================
Pacer trackPacer(true,STATS_UPDATE_MS);
void setTrackSpeed(int trackID, float speed, bool forceWrite)
{

    speed = constrain(speed, 0.0f, 1.0f);


    int vmax = getMaxDACValue(trackID); // Ge the max value to scale againt the throttle

    int vstart = (trackID == TRACK_ID::LEFT)    // Any values lower than vstart result in the motor being off, so start at this value
             ? cfg.settings.LEFT_DAC_START
             : cfg.settings.RIGHT_DAC_START;

    int dac = vstart + speed * (vmax - vstart);
    dac = constrain(dac, 0, vmax);

    static int lastDAC[2] = {-1, -1};



    if (dac != lastDAC[trackID] || forceWrite) {

        if (trackID == 0)
            mcp.setChannelValue(MCP4728_CHANNEL_A, dac);
        else
            mcp.setChannelValue(MCP4728_CHANNEL_B, dac);

        lastDAC[trackID] = dac;
    }
    
    if(false)//trackPacer.Pace())
    {
        Serial.print(F("Left DAC: ")); Serial.print(lastDAC[0]); Serial.print(F("  Right DAC: ")); Serial.println(lastDAC[1]);
    }
}

// =====================
// THROTTLE MAP
/**
 * Convert a normalised throttle input (0.0-1.0) into a normalised
 * speed demand (0.0-1.0).
 *
 * The mapping consists of three regions:
 *
 *  1) Deadband
 *     Inputs below THROTTLE_DEADBAND return zero output. This removes
 *     sensor noise and prevents unintended vehicle movement.
 *
 *  2) Take-up region
 *     Between THROTTLE_DEADBAND and TAKEUP_END a quadratic curve is
 *     applied, producing an output range of 0.0-0.1. This provides
 *     fine low-speed control and reduces the tendency for the vehicle
 *     to "jump" as movement begins.
 *
 *  3) Main throttle region
 *     Above TAKEUP_END the remaining throttle travel is scaled to
 *     produce an output range of 0.1-1.0. The DriveProfile
 *     curveExponent controls throttle feel:
 *
 *         1.0 = linear
 *        >1.0 = softer response
 *        <1.0 = more aggressive response
 *
 * A small full-throttle override ensures 100% output can always be
 * reached even if the calibrated throttle never quite reaches 1.0.
 *
 * @param t        Normalised throttle input (0.0-1.0)
 * @param profile  Active drive profile defining throttle shaping
 *
 * @return Normalised speed demand (0.0-1.0)
 */
float mapThrottle(float t, const DriveProfile& profile)
{

    if (t < cfg.settings.THROTTLE_DEADBAND)
        return 0.0f;

    if (t < cfg.settings.TAKEUP_END) {
        float x = (t - cfg.settings.THROTTLE_DEADBAND) / (cfg.settings.TAKEUP_END - cfg.settings.THROTTLE_DEADBAND);
        x = x * x;
        return x * 0.1f;
    }

    float x = (t - cfg.settings.TAKEUP_END) / (1.0f - cfg.settings.TAKEUP_END);

    x = pow(x, profile.curveExponent);


    float out = 0.1f + x * 0.9f;

    if (t > 0.95f)
        return 1.0f;

    return out;

}
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
void loop() 
{   
    static float lastValue = -1.0f;
    handleSerial();

    float throttleVal = throttle.GetThrottle();

    DriveProfile* profile = SetModes();

    // Force a controlled re-ramp whenever the drive mode changes.
    // This prevents abrupt speed changes when transitioning between
    // normal, slow, reverse and brake profiles.
    if(displayNewSystemMode())
    {
        currentOutput = 0.0f;
    }

    float target = mapThrottle(throttleVal, *profile);

    float rampRate = (target > currentOutput) ?
                 profile->rampUp :
                 profile->rampDown;

    currentOutput += (target - currentOutput) * rampRate;

 
    // Trim is applied based on the final commanded output rather than
    // raw throttle position so that interpolation follows the actual
    // speed demand after throttle shaping and ramp limiting.
    float trim = getInterpolatedTrim(currentOutput);

        
    // Calibration requires identical left/right outputs so that
    // measured RPM differences reflect drivetrain imbalance only.
    // If we are calibrating the trim, do not apply a trim value!
    if(FORCE_OUTPUT > 0.0f )     
    {
        currentOutput = FORCE_OUTPUT;
        trim = 0.0f;      
    }

    float left  = currentOutput;
    float right = currentOutput;

    if (trim > 0.0f)            // +ve trim affects right trak, -ve trim affects left
    {
        right *= (1.0f - trim); // Trim value is percentage to reduce throttle value
    }
    else if (trim < 0.0f)
    {
        left *= (1.0f + trim); // trim is negative
    }
    
    bool forceDACWrite = false;     // If we have just dropped out of a mode pacer delay, force a write to the dac
    if(modePacer.Pace())
    {
        forceDACWrite = true;
    }

    if(modePacer.Running())
    {
        mcp.setChannelValue(MCP4728_CHANNEL_A, 0);
        mcp.setChannelValue(MCP4728_CHANNEL_B, 0);   
        if(currentOutput > 0.0f)
        {
            modePacer.PacerReset();     // Force zero output until throttle is released
        }
        currentOutput = 0.0f;
    }
    else
    {
        setTrackSpeed(TRACK_ID::LEFT, left, forceDACWrite);
        setTrackSpeed(TRACK_ID::RIGHT, right, forceDACWrite);
        newSystemMode &=~ SystemMode::MODECHANGE;
    }

   
    if(false)//serialPacer.Pace())
    {
        Serial.print(F("Throttle :")); Serial.println(currentOutput);
        Serial.print(F("Track L: "));
        Serial.print(left);
        Serial.print(F(" Track R: "));
        Serial.println(right); 
        showMode();
    }

    if(lcdPacer.Pace() && (abs(lastValue - currentOutput) >= 0.01))
    {
        lastValue = currentOutput;
        lcd.setCursor(5,1);
        lcd.print(">");
        barGraph.ShowBargraph(currentOutput);
    }

    // Toggle manoeuvring mode for each press of the mode button. Other mode bits are preserved.
    if(modeSwitch.Pressed())
    {
          newSystemMode ^= SystemMode::SLOWMODE;
    }

}

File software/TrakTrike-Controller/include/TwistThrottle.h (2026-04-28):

#ifndef __TWISTTHROTTLE_H__
#define __TWISTTHROTTLE_H__


#include <Arduino.h>

class TwistThrottle {
public:
    // =====================
    // CONFIG STRUCT
    // =====================
    struct Config {
        int pin;

        int minADC;     // full reverse
        int maxADC;     // full forward
        int centerADC;  // idle

        int deadband;   // ADC counts around center

        float filterAlpha;   // 0.0 → 1.0 (lower = smoother)
        float maxRate;       // max change per update (units/sec), 0 = disabled

        int validMin;   // safety range
        int validMax;
    };

    // =====================
    // INIT
    // =====================
    void begin(const Config& cfg) {
        config = cfg;
        pinMode(config.pin, INPUT);

        filtered = config.centerADC;
        lastOutput = 0.0f;
        lastTime = millis();
    }

    // =====================
    // MAIN API
    // =====================
    float GetThrottle() {

        int raw = analogRead(config.pin);

        // ---- Safety check ----
        if (raw < config.validMin || raw > config.validMax) {
            fault = true;
            return 0.0f;
        }

        fault = false;

        // ---- Filtering (IIR) ----
        filtered += (raw - filtered) * config.filterAlpha;

        // ---- Deadband around centre ----
        if (abs(filtered - config.centerADC) < config.deadband) {
            return applyRateLimit(0.0f);
        }

        // ---- Map to -1.0 → +1.0 ----
        float output;

        if (filtered > config.centerADC) {
            float span = config.maxADC - config.centerADC;
            output = (filtered - config.centerADC) / span;
        } else {
            float span = config.centerADC - config.minADC;
            output = (filtered - config.centerADC) / span;
        }

        // Clamp
        output = constrain(output, -1.0f, 1.0f);

        return applyRateLimit(output);
    }

    // =====================
    // STATUS
    // =====================
    bool isFault() const {
        return fault;
    }

private:
    Config config;

    float filtered = 0;
    float lastOutput = 0;
    unsigned long lastTime = 0;

    bool fault = false;

    // =====================
    // RATE LIMITER
    // =====================
    float applyRateLimit(float target) {

        if (config.maxRate <= 0.0f)
            return target;

        unsigned long now = millis();
        float dt = (now - lastTime) / 1000.0f;
        lastTime = now;

        float maxDelta = config.maxRate * dt;
        float delta = target - lastOutput;

        if (delta > maxDelta) delta = maxDelta;
        if (delta < -maxDelta) delta = -maxDelta;

        lastOutput += delta;

        return lastOutput;
    }
};


#endif // __TWISTTHROTTLE_H__

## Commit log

2026-05-19 Removed debug. Changed startup delay to 100ms. Set real world DAC_START and THROTTLE_MIN/MAX_ADC
2026-05-21 Improved Invalid Calibration error message
    [main.cpp]
2026-05-21 Added reverse and brake switch operation
    [~TrakTrike4.sch]
2026-05-22 Left track not workng because needs to be at 0V for a few seconds at power up. Changed default DAC value to 0
    [main.cpp]
2026-05-23 Added table interpolated trim. Added 'force' command. Added calibrate command
2026-05-24 Throttle display working
2026-05-24 Fixed corrupted string print when using printTrimValues
    [main.cpp]
2026-05-24 Added trimThrottlePoints to 'calibrate' command
2026-06-04 Improved forlder layout. Added extra documentation
    [~TrakTrike4.sch]
2026-06-04 Update README with PCB details and sponsorship link
    Added information about PCB creation and sponsorship.
2026-06-05 Changed mode change throttle pacer to 500ms. Norm/Slow mode change now activates throttle pacer. If a mode change is detected, throttle pacer remains active until physical throttle is zero
2026-06-05 Update README with custom PCB details
    Added information about custom PCB from PCBWay to the components list.
2026-06-05 Add Mode Change Interlock section to README
    Added a section on Mode Change Interlock to explain safety measures during mode changes with active throttle.
2026-06-05 Change PCBWay discount link to project files link
    Updated PCBWay link for project files.
2026-06-05 Update README to improve clarity on controller issues
    Clarified issues with low-speed throttle behavior and controller speed discrepancies.
2026-06-05 Removed mode pacer activation when brake applied. BRKE now shows immediately
2026-06-24 Added reset of modepacer when brake is first applied. Updated readme
    [main.cpp]
2026-06-26 Added BOM. Changed power up LCD title
    [BOM.xlsx]
2026-06-28 Clarify project description in README
    Added pusher to vehicle type description. This is not a board for track steer vehicles
2026-07-01 Update README with project details and safety instructions
    Clarified project description and added safety note for vehicle calibration procedures.
